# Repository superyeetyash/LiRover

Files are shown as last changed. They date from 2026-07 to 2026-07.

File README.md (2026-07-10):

# LiRover, Curated by Alex, Anish, Om, Yash

## Overview

Welcome to LiRover! This hardware for Hackclub's Stardance event will be centered around a hardware initiative by 4 high schoolers.

After a failed rocket idea, we settled on an RC car with a LiDAR sensor attached that can create a comprehensive map of its surroundings. This is done from scratch by creating a 3D printed chassis, custom PCB, and an embedded control system. This project is controlled through a Raspberry Pi Zero 2 W and a Raspberry Pi Pico W. The robot will combine LiDAR sensing, an IMU (which includes an accelerometer for linear acceleration, gyroscope for measuring angular rotation, and magnetometer for magnetic field and acting as a compass), motor drivers, and wheel odometry to estimate its position and generate a real-time 2D "minimap" of its surrounding area. To control it, we implemented a Bluetooth module for SLAM development (Simultaneous Localization and Mapping, essentially enabling the robot to construct a map and track its position).

---

## Features

- Custom CAD and 3D-printed chassis for the RC car
- Custom PCB with onboard power regulation, fusing, and dedicated LiDAR/motor connectors
- Bluetooth remote control
- Real time LiDAR mapping
- IMU-based tracking
    - Accelerometer for linear acceleration
    - 3-plane gyroscope for angular rotation
    - Magnetometer for magnetic field detection

---

## Hardware

### Computing
- Raspberry Pi Zero 2 W
- Raspberry Pi Pico W

### Sensors
- 2D/3D Lidar
- IMU
- Wheel Encoders (??)

### Electronics
- Custom PCB (Pico W + Pi Zero 2 W header, LiDAR connector, screw terminals for motor/battery)
- Motor driver
- Lithium Battery Pack
- Voltage regulation circuitry
- Bluetooth module
- Onboard fuse protection

### Mechanical
- Fully custom 3D-printed chassis
- Custom motor mounts
- 3D-printed power switch housing

---

## Software

### Raspberry Pi Zero 2 W
- Sensor fusion
- Mapping
- Localization
- Bluetooth comms
- Dashboard server
- Robot logic / Robot comms

### Raspberry Pi Pico W (*Communicates with the Raspberry Pi Zero 2 W*)
- Sensor reading
- Motor Pulse Width Modulation (PWM)
- Encoder Feedback

---

## Project Goals

- Design and develop a complete robotics platform
- Develop an embedded control system
- Generate a live 2D map using LiDAR and motion estimation (Main goal!!!)

---

<picture>
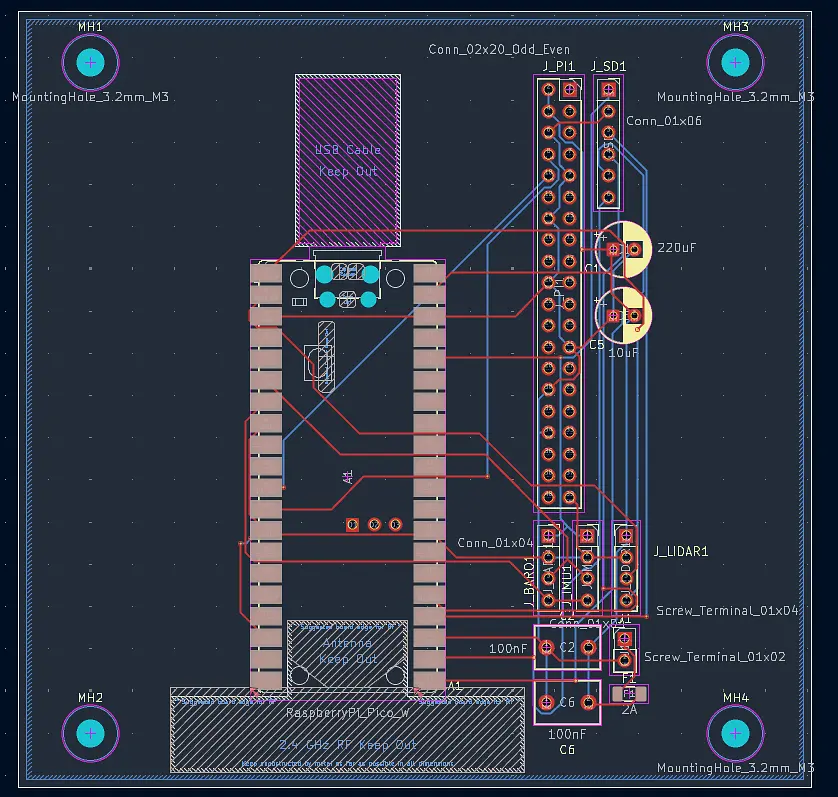
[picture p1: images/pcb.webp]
PCB diagram
  
</picture>

<picture>
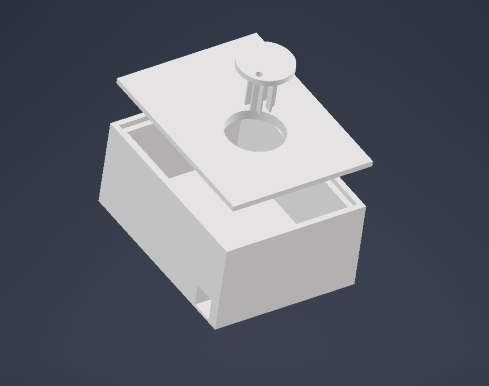
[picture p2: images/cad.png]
CAD model
 
</picture>

---

## Parts List

PARTS LIST IS IN BOM.csv

---

## Repository Structure

_Coming Soon!!_

---

## Devlog

Check out [JOURNAL.md](./JOURNAL.md) for build progress and updates.

---

## License

This project is licensed with the MIT License.

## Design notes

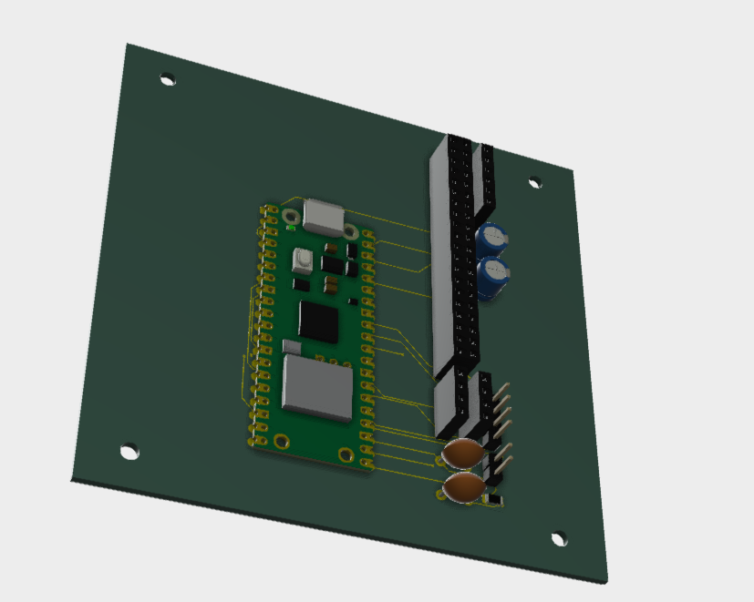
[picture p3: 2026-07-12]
images/pcbrender.png

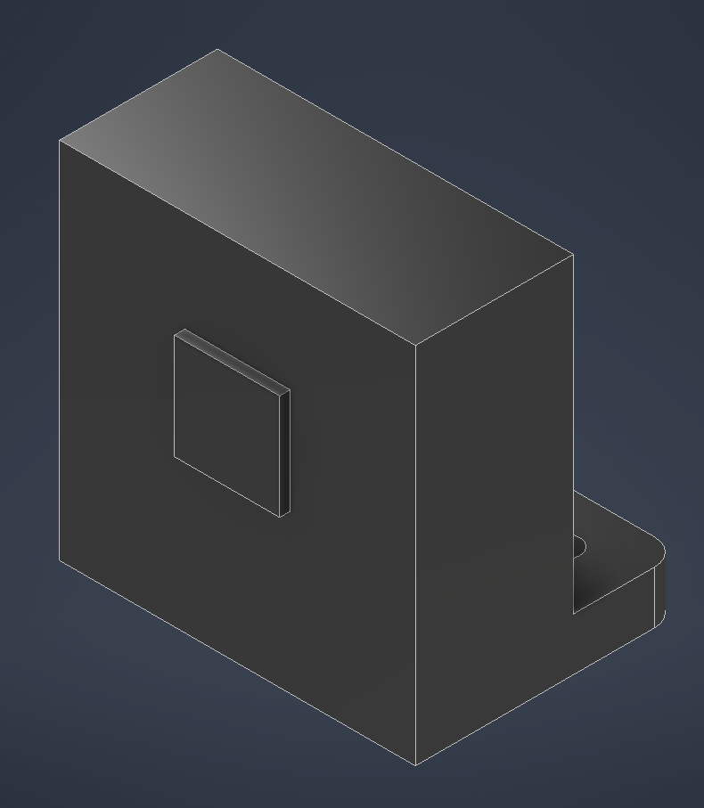
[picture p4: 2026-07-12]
images/lidar.png

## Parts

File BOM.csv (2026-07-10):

Item | Link | Price | Final Price | Notes
Arduino Uno R3 (Elegoo Super Starter Kit) | https://www.amazon.com/ELEGOO-Project-Tutorial-Controller-Projects/dp/B01D8KOZF4 | $44.99 | $48.36 | confirmed + 7.5% tax
Arduino to USB-A Cable | https://www.amazon.com/Usb-Cable-A-B-For-Arduino/dp/B01JOQ2G3Y | $5.99 | $6.44 | estimate + 7.5% tax
Assorted wires (M-M, M-F, F-F) | https://us.elegoo.com/products/elegoo-multicolored-dupont-wire-kit | $6.59 | $6.59 | confirmed, Elegoo site
Raspberry Pi Zero 2 W | https://www.raspberrypi.com/products/raspberry-pi-zero-2-w/ | $15.00 | $15.00 | confirmed, official
Raspberry Pi Pico W | https://www.raspberrypi.com/products/raspberry-pi-pico/ | $6.00 | $6.00 | confirmed, official
LiDAR (Benewake TF03-180, used, UART) | https://www.ebay.com/itm/127916899611 | $80.89 | $86.96 | shipping + tax
SparkFun 9DoF IMU Breakout (ISM330DHCX + MMC5983MA) | https://www.digikey.com/en/products/detail/sparkfun-electronics/19895/16672285 | $45.74 | $45.74 | kept as given
Adafruit BMP388 Pressure Sensor | https://www.digikey.com/en/products/detail/adafruit-industries-llc/3966/9685338 | $9.95 | $9.95 | kept as given
Adafruit MicroSD SPI/SDIO Breakout | https://www.digikey.com/en/products/detail/adafruit-industries-llc/4682/12822319 | $3.50 | $3.50 | kept as given
DigiKey shipping + tax + tariff | - | $13.08 | $13.08 | $8.49 ship + $4.31 tax + $0.28 tariff
MicroSD Card (Samsung PRO Endurance 32GB) | https://www.amazon.com/Samsung-Endurance-32GB-Micro-Adapter/dp/B07B98GXQT | $10.99 | $11.81 | confirmed MSRP + 7.5% tax
Pololu 5V Step-Up Regulator (U1V11F5) | https://www.pololu.com/product/2562 | $7.95 | $7.95 | kept as given
Pololu shipping & handling | - | $6.95 | $6.95 | kept as given
Battery holder (2-pack, 8x AA, 12V) | https://www.amazon.com/LAMPVPATH-Battery-Holder-Leads-Double-batteries/dp/B07KVHMQRH | $16.29 | $17.51 | confirmed via Newegg + 7.5% tax
Continuous rotation servo | https://www.amazon.com/Wishiot-TD-8135MG-Digital-Waterproof-500%CE%BCs-2500%CE%BCs/dp/B08JCVLSCK | $28.94 | $31.11 | estimate + 7.5% tax
Motor driver (TB6612FNG) | https://www.amazon.com/DIANN-TB6612FNG-Stepper-Driver-Module/dp/B0BLRSWTLM | $8.39 | $9.02 | estimate + 7.5% tax
Bluetooth module (HC-05, for Dabble) | https://www.amazon.com/HiLetgo-Wireless-Bluetooth-Transceiver-Arduino/dp/B071YJG8DR | $10.28 | $11.05 | estimate + 7.5% tax
Gear motors (2-pack, N30 micro, 12V) | https://www.amazon.com/BRINGSMART-Micro-Gearbox-Diameter-Reduction/dp/B0GWQVLZFF | $17.58 | $18.90 | estimate + 7.5% tax
Gear motor wheels | https://www.amazon.com/ThtRht-Motor-Wheels-Replacement-Smart/dp/B0CG1C7T8J | $10.00 | $10.75 | estimate + 7.5% tax
Caster wheel (360 deg, best judgment) | https://www.amazon.com/Heavy-Rubber-Caster-Wheel-Swiveling/dp/B004672ZGA | $17.50 | $18.81 | best guess, not confirmed + 7.5% tax
Batteries (AA, pack) | https://www.amazon.com/Energizer-Batteries-Pack-Double-Alkaline/dp/B0D51LH5Y5 | $12.00 | $12.90 | estimate + 7.5% tax
DROK LM2596 buck converter | https://www.amazon.com/DROK-Display-LM2596-Buck-Converter/dp/B019RKVMKU | $9.00 | $9.67 | estimate, midpoint of $8-10 + 7.5% tax
Subtotal before tax | - | $388.71 | - | -
GRAND TOTAL | - | - | $406.07 | -

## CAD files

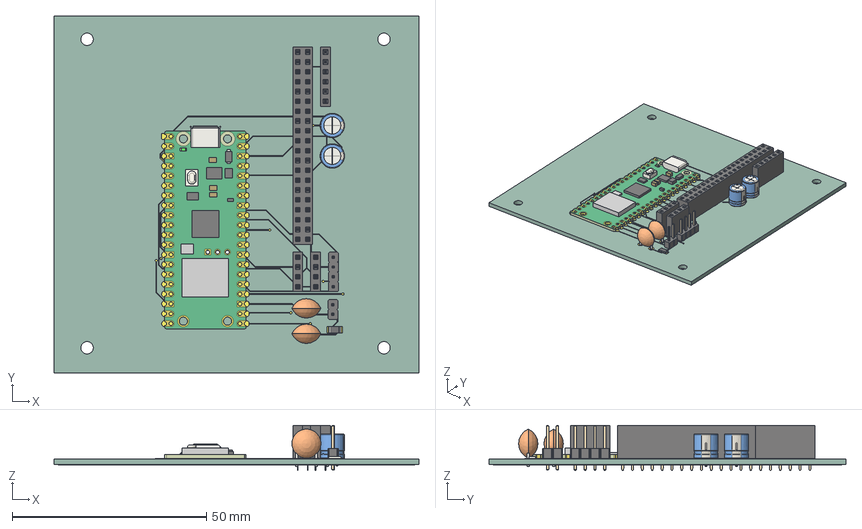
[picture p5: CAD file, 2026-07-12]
cad/PCB.step
94.0 x 92.0 x 11.6 mm
PinSocket_2x20_P2.54mm_Vertical
Fuse_1206_3216Metric
PinHeader_1x02_P254mm_Vertical
CP_Radial_D63mm_P250mm x 2
PinSocket_1x04_P2.54mm_Vertical x 2
PinSocket_1x06_P2.54mm_Vertical
C_Disc_D75mm_W50mm_P500mm x 2
RaspberryPi_Pico_W_Module_KiCad
PinHeader_1x04_P254mm_Vertical
pcb_copper
pcb_PCB

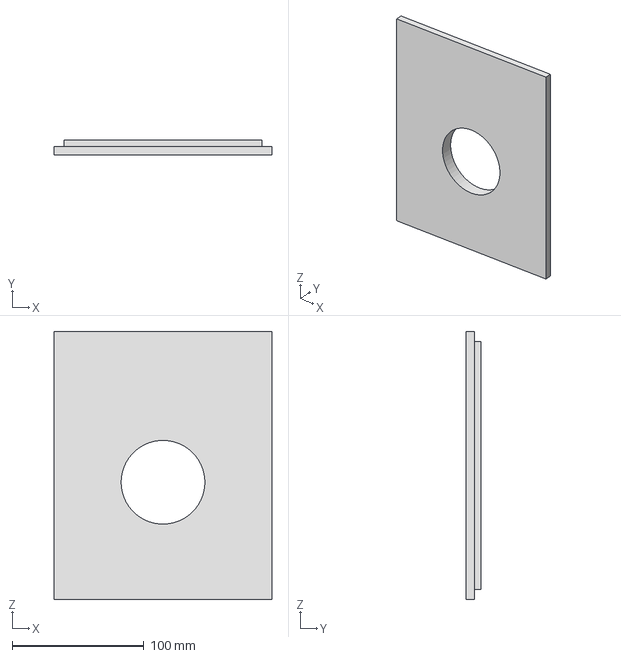
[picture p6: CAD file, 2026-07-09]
cad/OGRobotRoof.stp
165.1 x 11.4 x 203.2 mm

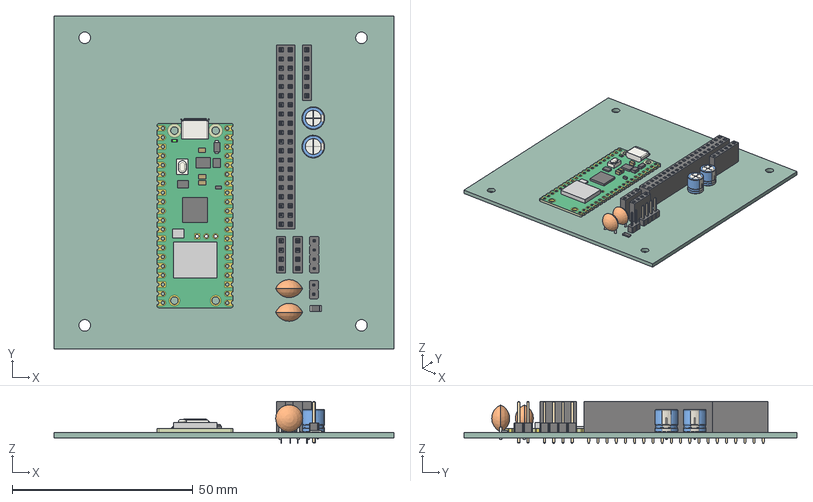
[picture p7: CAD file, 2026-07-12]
pcb/pcb.step
94.0 x 92.0 x 11.6 mm
PinSocket_2x20_P2.54mm_Vertical
Fuse_1206_3216Metric
PinHeader_1x02_P254mm_Vertical
CP_Radial_D63mm_P250mm x 2
PinSocket_1x04_P2.54mm_Vertical x 2
PinSocket_1x06_P2.54mm_Vertical
C_Disc_D75mm_W50mm_P500mm x 2
RaspberryPi_Pico_W_Module_KiCad
PinHeader_1x04_P254mm_Vertical
pcb_PCB

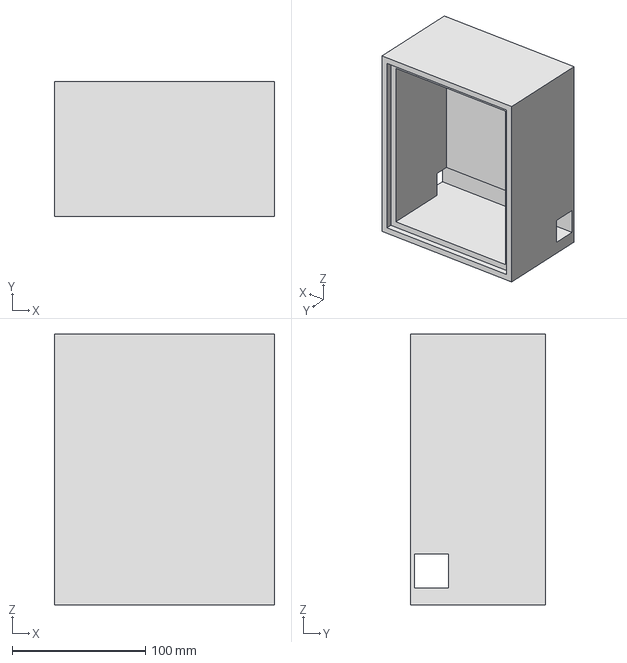
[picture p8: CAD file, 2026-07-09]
cad/OGRobotBase.stp
165.1 x 101.6 x 203.2 mm

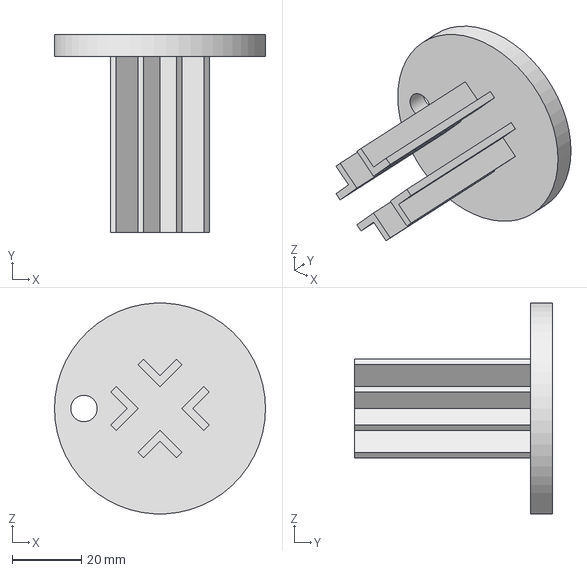
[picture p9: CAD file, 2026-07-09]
cad/OGPlatform.stp
61.0 x 57.1 x 60.9 mm

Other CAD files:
cad/OGCasterWheel.ipt
cad/OGGearMotor.ipt
cad/OGLiDAR.ipt
cad/OGPCB.ipt
cad/OGPlatform.ipt
cad/OGRobotAssembly.iam
cad/OGRobotBase.ipt
cad/OGRobotRoof.ipt
cad/OGWheel.ipt

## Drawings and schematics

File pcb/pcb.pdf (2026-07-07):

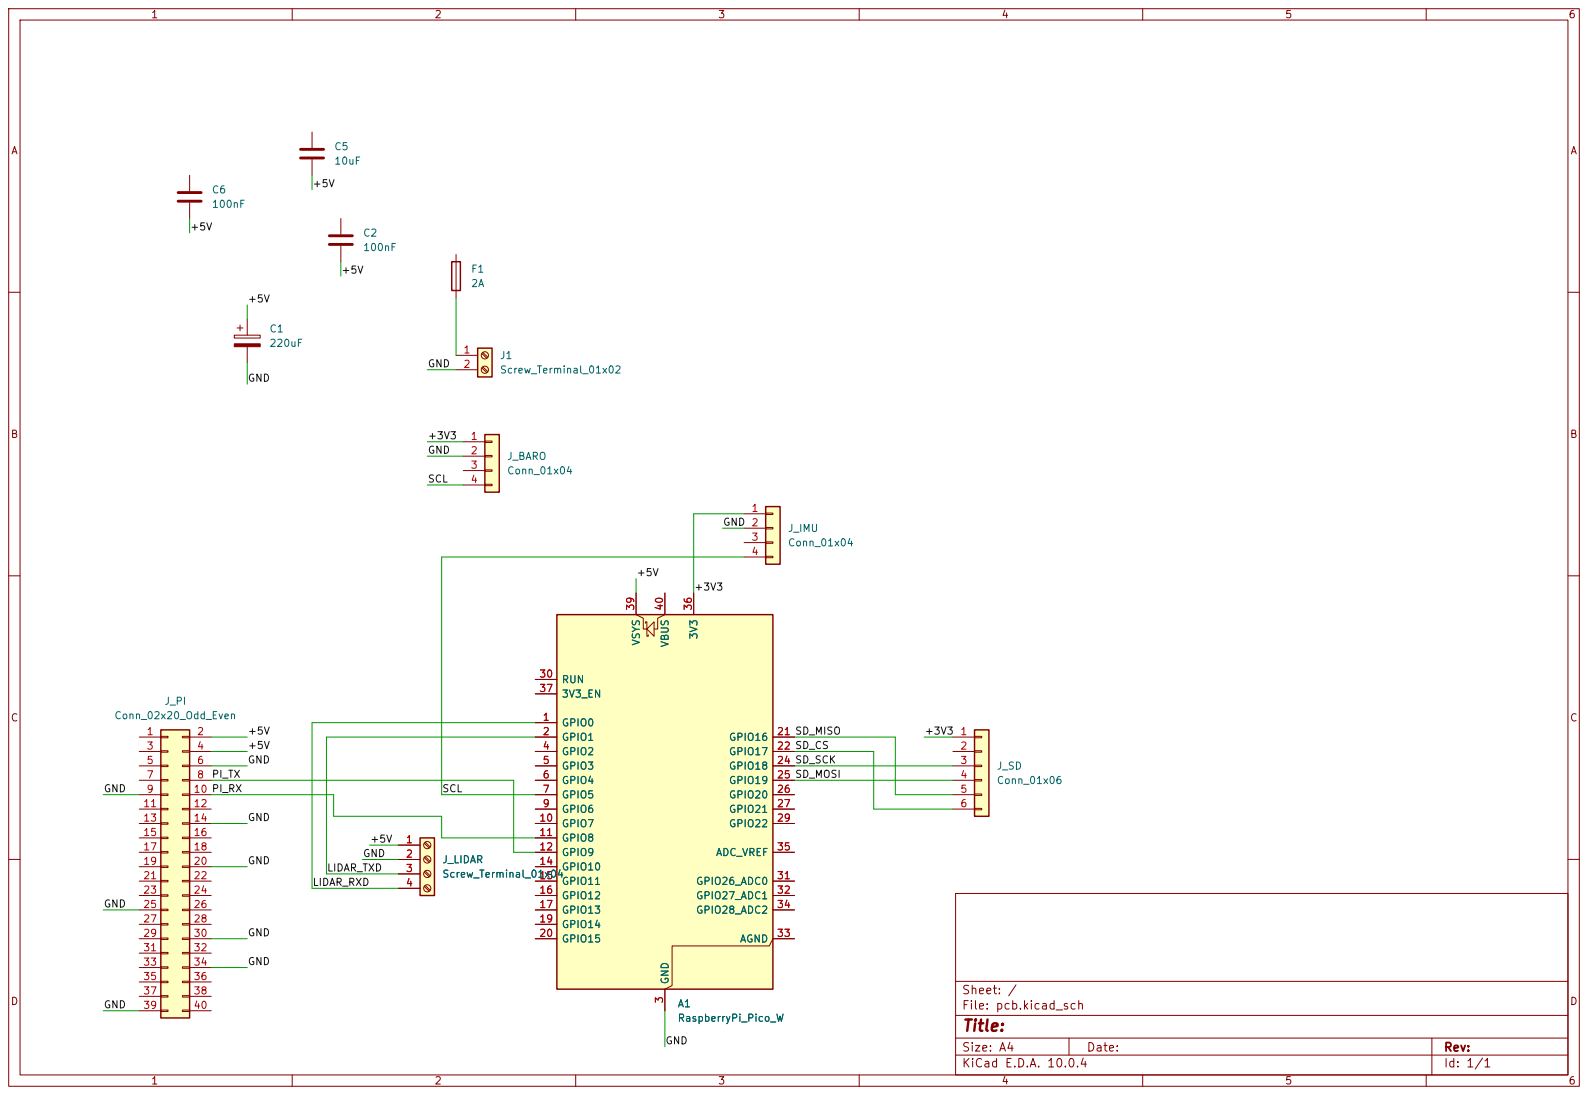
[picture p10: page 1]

Size: A4 | Rev:
KiCad E.D.A. 10.0.4 | Id: 1/1

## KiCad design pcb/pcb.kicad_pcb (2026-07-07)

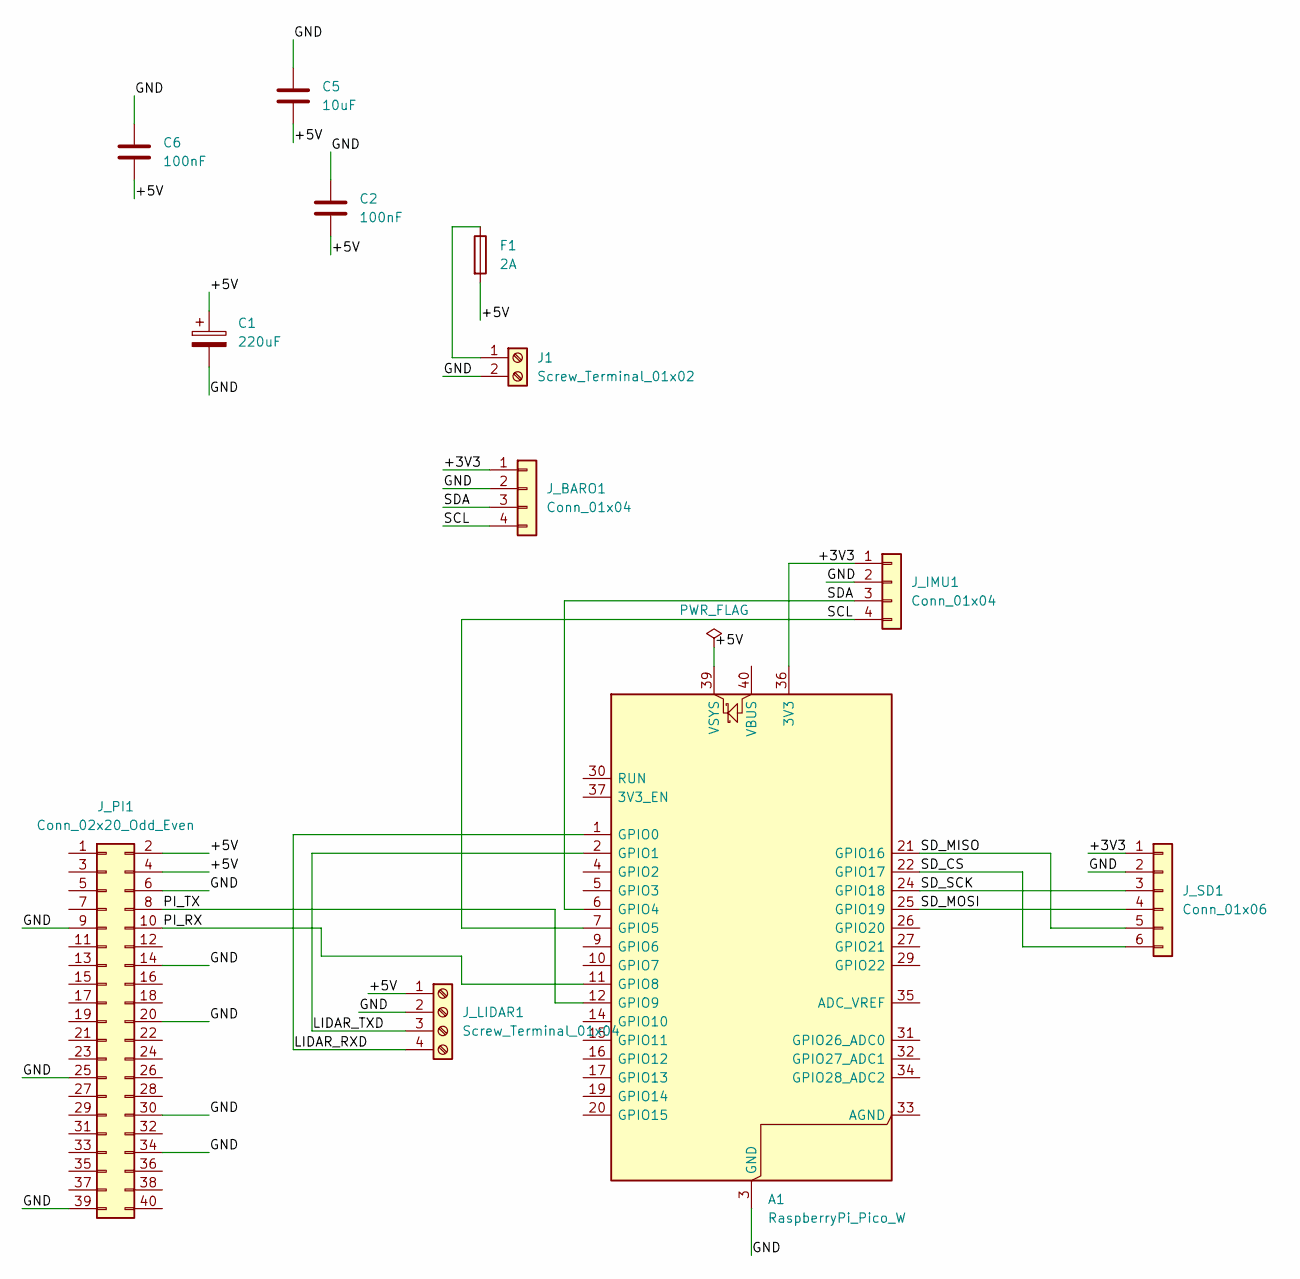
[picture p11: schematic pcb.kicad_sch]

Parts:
A1: RaspberryPi_Pico_W; RaspberryPi_Pico_W_SMD_HandSolder
C1: 220uF; CP_Radial_D6.3mm_P2.50mm
C2, C6: 100nF; C_Disc_D7.5mm_W5.0mm_P5.00mm
C5: 10uF; CP_Radial_D6.3mm_P2.50mm
F1: 2A; Fuse_1206_3216Metric
J1: Screw_Terminal_01x02; PinHeader_1x02_P2.54mm_Vertical
J_BARO1: Conn_01x04; PinSocket_1x04_P2.54mm_Vertical
J_IMU1: Conn_01x04; PinSocket_1x04_P2.54mm_Vertical
J_LIDAR1: Screw_Terminal_01x04; PinHeader_1x04_P2.54mm_Vertical
J_PI1: Conn_02x20_Odd_Even; PinSocket_2x20_P2.54mm_Vertical
J_SD1: Conn_01x06; PinSocket_1x06_P2.54mm_Vertical

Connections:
/+3V3: A1.36 (3V3), J_BARO1.1, J_IMU1.1, J_SD1.1
/+5V: A1.39 (VSYS), C1.1, C2.2, C5.2, C6.2, F1.2, J_LIDAR1.1, J_PI1.2, J_PI1.4
/GND: A1.3 (GND), A1.8 (GND), A1.13 (GND), A1.18 (GND), A1.23 (GND), A1.28 (GND), A1.38 (GND), C1.2, C2.1, C5.1, C6.1, J1.2, J_BARO1.2, J_IMU1.2, J_LIDAR1.2, J_PI1.6, J_PI1.9, J_PI1.14, J_PI1.20, J_PI1.25, J_PI1.30, J_PI1.34, J_PI1.39, J_SD1.2
/LIDAR_RXD: A1.1 (GPIO0), J_LIDAR1.4
/LIDAR_TXD: A1.2 (GPIO1), J_LIDAR1.3
/PI_RX: A1.11 (GPIO8), J_PI1.10
/PI_TX: A1.12 (GPIO9), J_PI1.8
/SCL: A1.7 (GPIO5), J_BARO1.4, J_IMU1.4
/SDA: A1.6 (GPIO4), J_BARO1.3, J_IMU1.3
/SD_CS: A1.22 (GPIO17), J_SD1.6
/SD_MISO: A1.21 (GPIO16), J_SD1.5
/SD_MOSI: A1.25 (GPIO19), J_SD1.4
/SD_SCK: A1.24 (GPIO18), J_SD1.3
unnamed: F1.1, J1.1

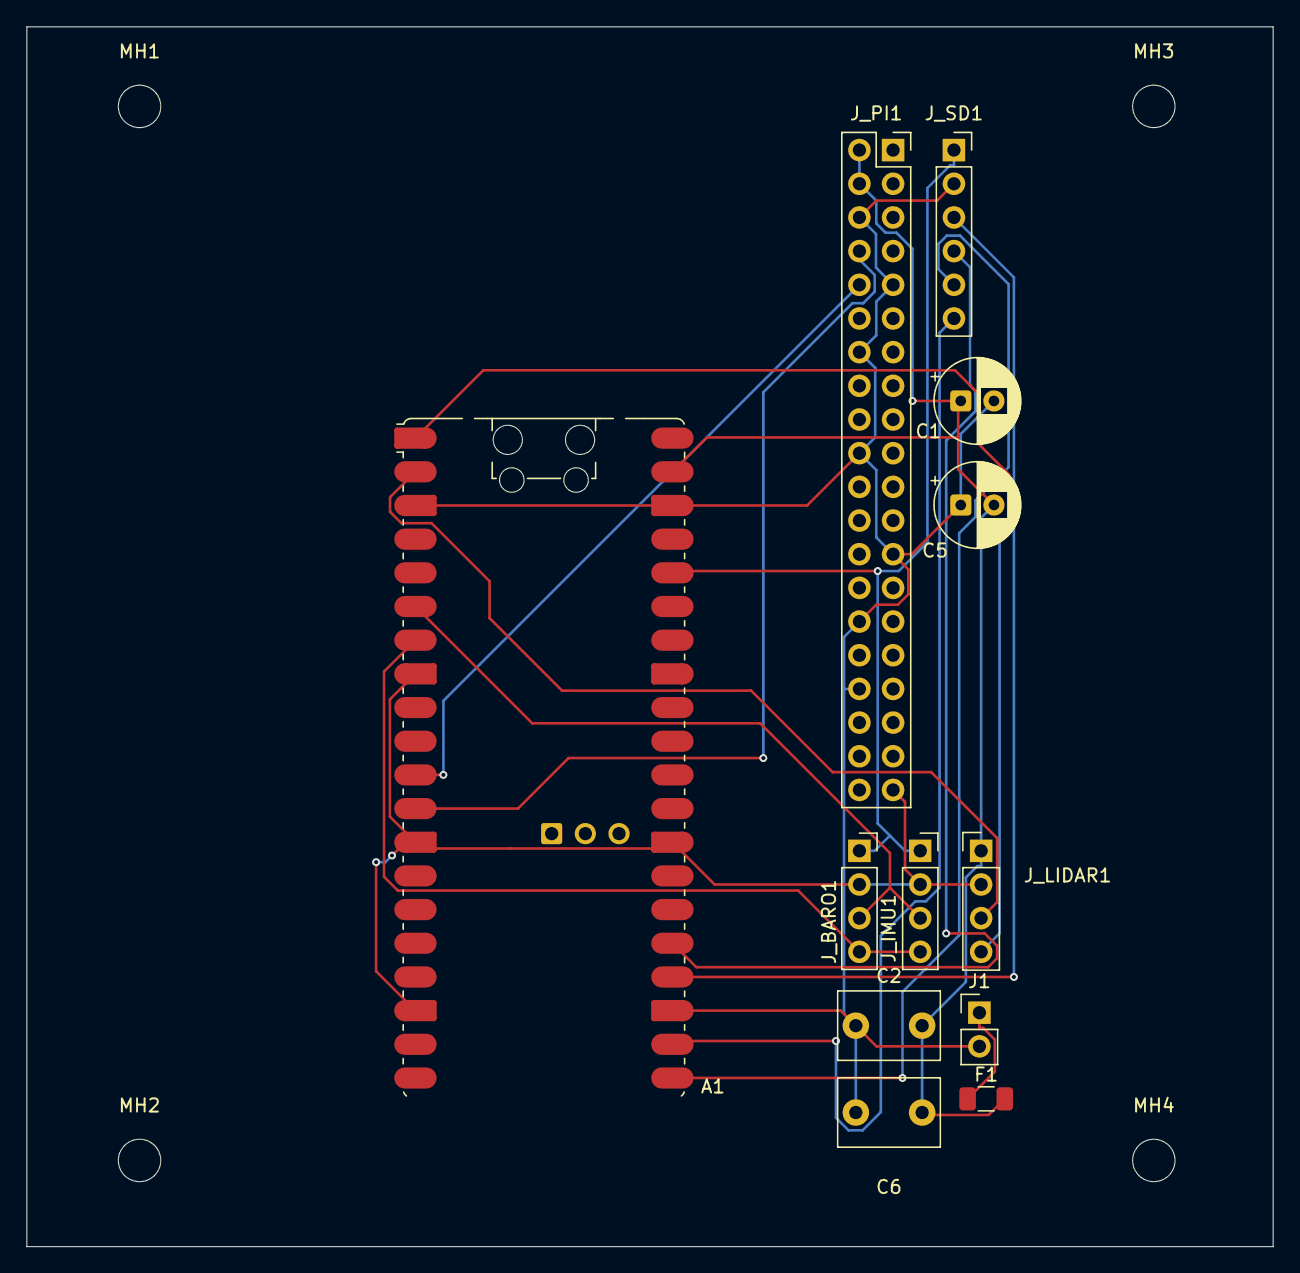
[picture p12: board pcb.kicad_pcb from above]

Board: 2 copper layers, 94.0 x 92.0 mm, 16 parts (0 on the bottom side), 14 nets.

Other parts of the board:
MH1, MH2, MH3, MH4: MountingHole_3.2mm_M3

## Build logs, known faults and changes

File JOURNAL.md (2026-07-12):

# LiRover Journal

Trying to actually keep this updated as we go instead of writing it all after the fact. Dates below line up with when stuff actually got committed.

## 6/12 (~1 hr) -- repo opened

Started the repo. At this point the plan wasn't LiRover at all, it was a rocket project (there's a "StarPost" folder from this era that stuck around in git history for a couple weeks before we killed it). Mostly just got the repo and a license set up this session.

## 6/17 (~1 hr) -- README pass

Small session, just cleaning up the README for the rocket idea. Nothing structural.

## 6/20 (~3 hrs) -- README rewrite + legal research

Two commits back to back this evening, "Created README" and thated legal requirements" seventeen minutes later. The legalresearch took most of the time here, rockets bring in a lot more regulatory stuff than we'd realized (airspace, motor classification, that kind of thing) and it started to feel like a lot for a hackclub timeline.

## 6/28 (~4 hrs) -- scrapped the rocket, pivoted to the rover

This was the actual pivot. Three commits four minutes apart la11:09 PM): rewrote the README from scratch for the new idea,

Once we landed on it, it also just made things easier: less regulation, cheaper parts, and something we could actually test indoors instead of needing a field.

## 6/29 (~2 hrs) -- project structure

Set up the actual folder skeleton, one commit, 53 files, most of them empty `.gitkeep` placeholders: `cad`, `pcb`, `firmware` (split into `arduino` and `raspberry_pi`, since the Pico and the Pi Zero are doing pretty different jobs), `hardware`, `dashboard`, `docs`, `tests`. Didn't write any actual code this session, just wanted the folders to exist so we weren't arguing about where things go later once we're all in here at the same time.

## 7/7 (~6 hrs) -- the PCB

This was the big one. Before this the board only existed as a sketch on paper and a lot of talking. This session we actually sat down in KiCad and laid it out for real, then merged it back into main (that merge — "Ress kind of messy, there'd been parallel work happening and weended up resolving a chunk of conflicts by hand instead of a clean merge, nothing lost, just took longer than it should have).

PCB layout in KiCad, showing the Pico W footprint, keepout zones, connectors, and mounting holes

Board's built around the Pico W, with the Pi Zero's 40-pin header right next to it so the two boards can talk without a rat's nest of jumper wires. Added a 6-pin header for the microSD breakout too, so logging isn't PIO.
instead of soldering the motor and battery leads directly to the board. We're going to be pulling this thing apart constantly over the next few weeks, and re-soldering every time we swap a battery or a motor would've gotten old fast.

Also threw three keepout zones over the Pico: one for the USB cable, one for the antenna, one just labeled "2.4 GHz RF Keep Out" so nobody routes a trace under the wireless section without noticing. These are rough right now, eyeballed off the datasheet instead of the real footprint, so before this goes anywhere near a fab we need to check them against the actual Pico W footprint in KiCad.

Four M3 mounting holes, one in each corner, so the board can actually bolt to the chassis instead of sitting loose.

Gerbers and the BOM folders are both still empty on purpose. Layout is "done for now," not "ready to order."

Also squeezed in an update to the parts list on the README thiects what we're buying now instead of an early guess.

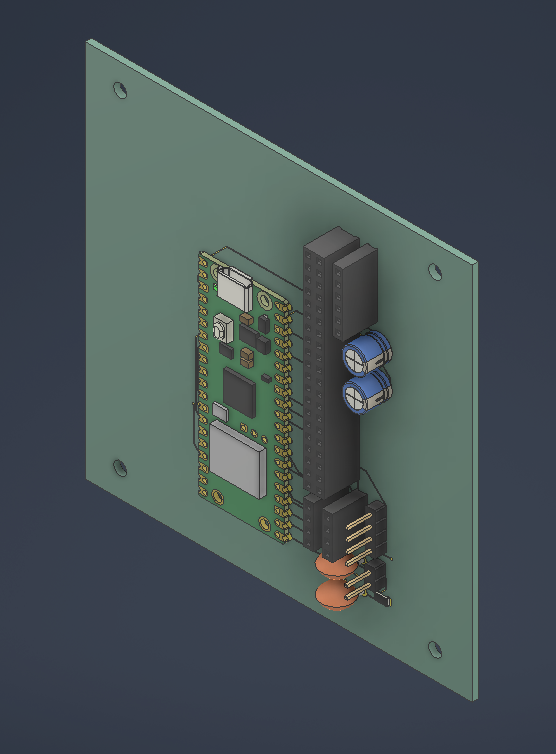
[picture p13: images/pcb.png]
PCB render


## 7/8 (~9 hrs) -- CAD, the switch housing, and getting it all

CAD render of the chassis and rover platform

**CAD (~4 hrs):** Got `OGPlatform`, `OGRobotBase`, and `OGRobotRoof` modeled and into the repo. `chassis` / `wheels` / `mounts` are modeled.

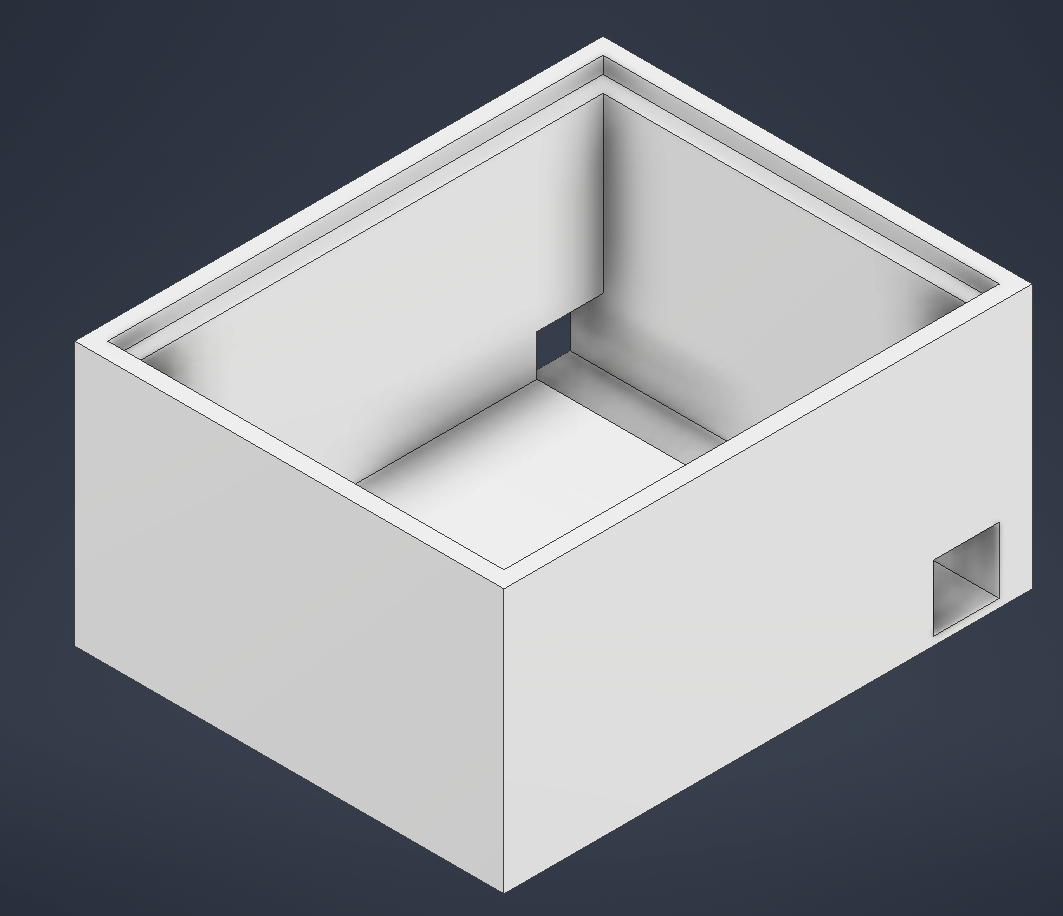
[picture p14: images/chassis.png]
chassis

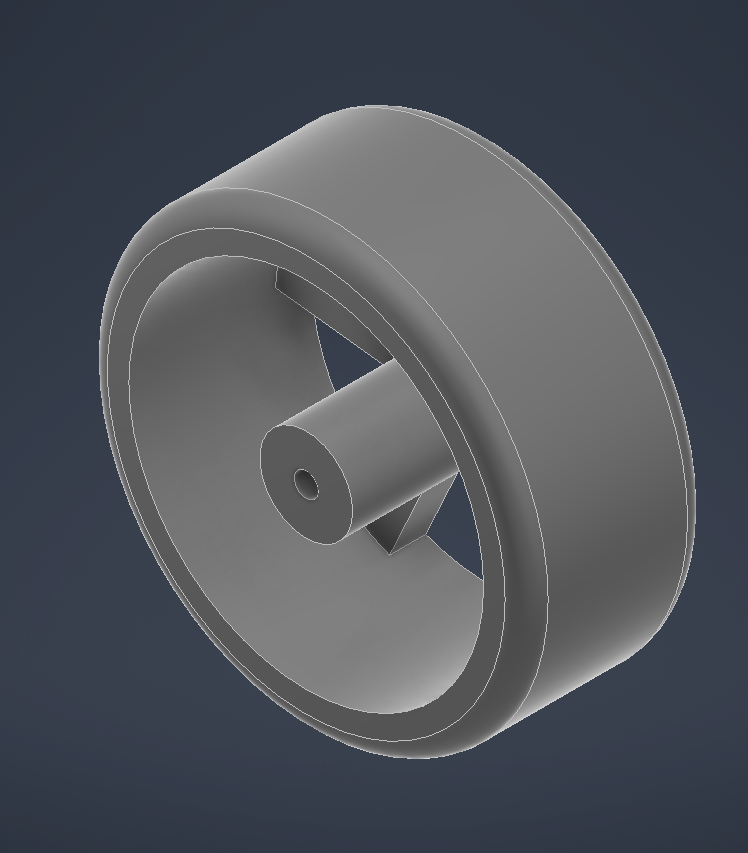
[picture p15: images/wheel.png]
wheel

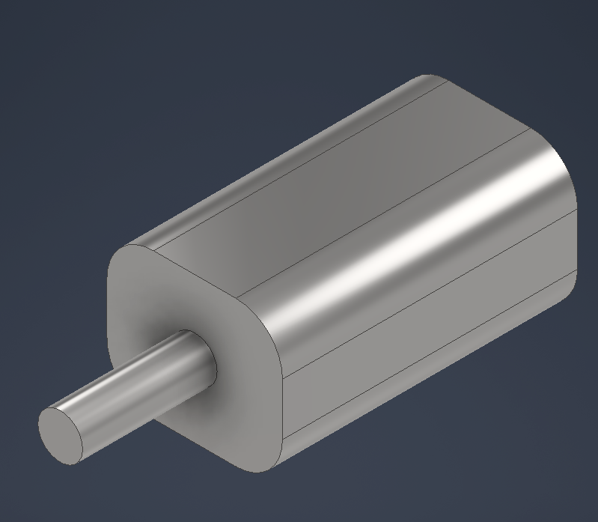
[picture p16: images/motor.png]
motor+mount


**Switch housing (~3 hrs):** Designed and printed a small enclosure for the power switch, a box with a lid that snaps on and a little post on the underside that the pushbutton rests against, so you can hit the switch without any bare wiring exposed underneath. First print fits close, but we haven't test-fit it against the real board yet, just the loose parts.

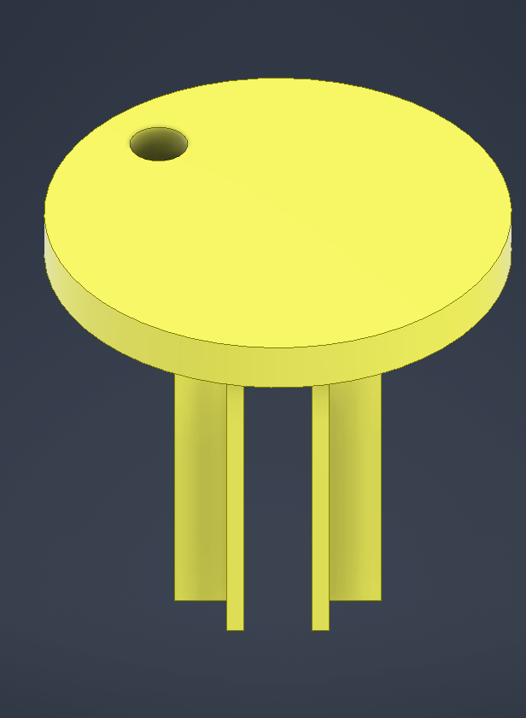
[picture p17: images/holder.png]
housing

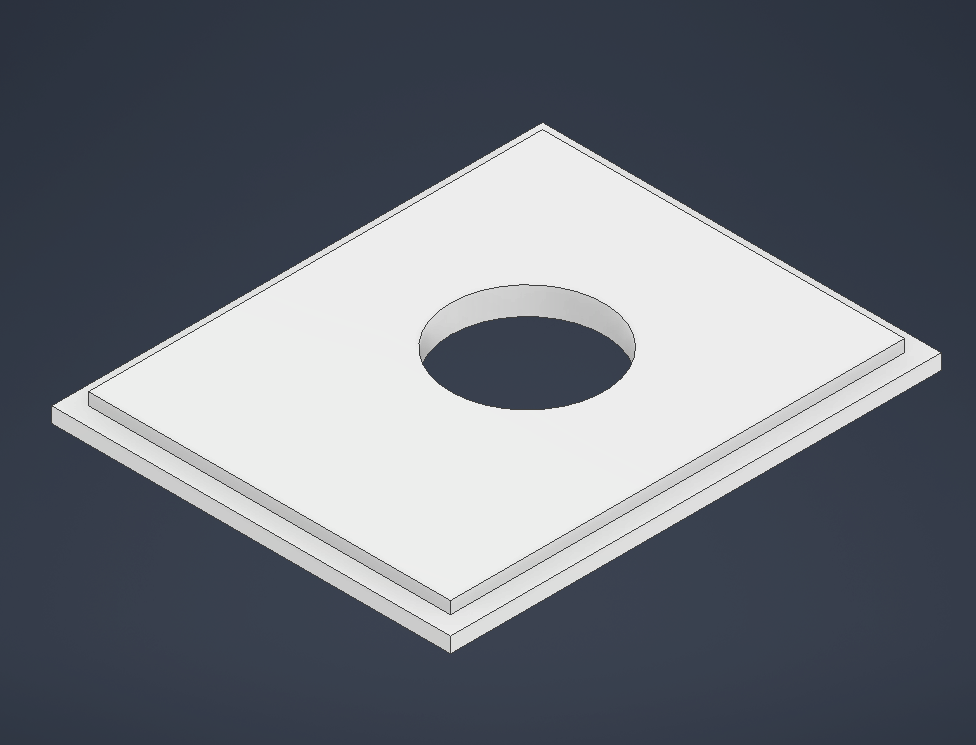
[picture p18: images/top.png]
top


**Images + final merge (~2 hrs):** Got reference photos of the PCB and the CAD render into the README so it's not just walls of text, plus a last merge to sync everything back to main.

Worth being honest that not everything is in the git log — sourcing/pricing parts, comparing LiDAR options before settling on the TF03, and general back-and-forth deciding on the pivot direction all ate real hours that never turned into a commit by themselves.

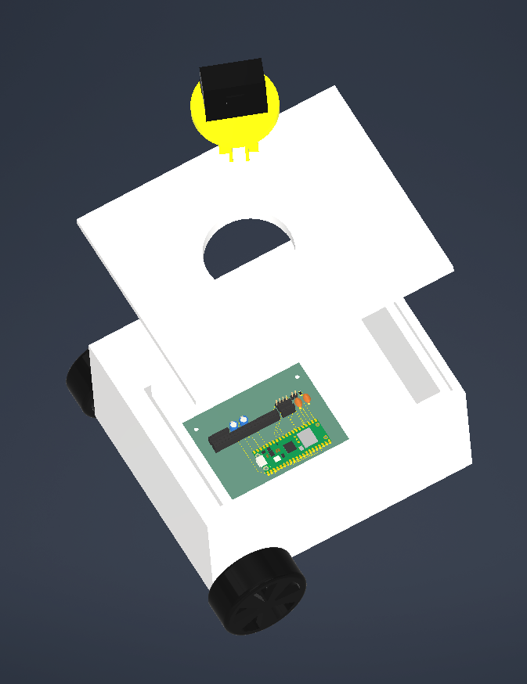
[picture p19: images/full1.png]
Top view

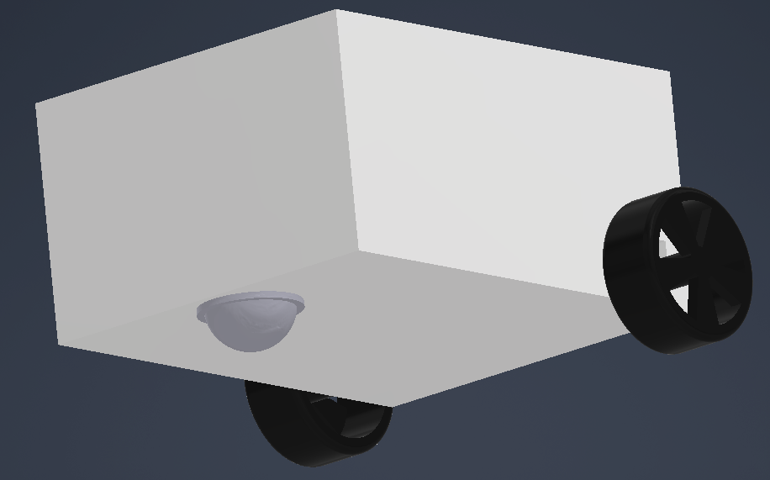
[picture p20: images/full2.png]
Bottom view


**Running total: ~32 hrs as a group so far.**

## What's not started yet

Firmware is empty on both the Pico and the Pi side (`main.ino`es). The dashboard folder (frontend and backend) is empty.`hardware/pinouts` and `hardware/wiring` don't have anything in them. None of the test folders have real tests yet. Basically everything past "the board and chassis exist" is still ahead of us.

## Next up

Wiring in the IMU and encoders now that the connectors are mostly locked in. Double-checking the RF/USB/antenna keepouts against the real Pico W footprint before we even think about ordering the board. Sorting the loose CAD files into their actual subfolders. And then actually starting firmware, since right now we've got a board and a chassis and basically zero code running on either.

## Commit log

2026-07-08 Include PCB and CAD images in README
    Added images of PCB diagram and CAD model to README.
2026-07-09 added cad files
    [OGPlatform.stp, OGRobotBase.stp, OGRobotRoof.stp]
2026-07-10 added BOM.csv
    [BOM.csv]
2026-07-10 Revise parts list and link to BOM.csv
    Updated parts list and removed detailed pricing information.
2026-07-10 Update LiDAR listing with new eBay link
    [BOM.csv]
2026-07-10 Modify LiDAR entry in BOM.csv
    Updated LiDAR entry and removed expired listing.
    [BOM.csv]
2026-07-10 Modify LiDAR price and update grand total
    Updated the price for LiDAR and adjusted the grand total.
    [BOM.csv]
2026-07-12 Rename Screenshot 2026-07-12 003204.png to pcbrender.png
2026-07-12 added last cad files and images
    [OGCasterWheel.ipt, OGGearMotor.ipt, OGLiDAR.ipt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]
